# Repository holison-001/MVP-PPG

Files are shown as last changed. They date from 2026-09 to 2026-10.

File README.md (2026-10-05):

# SleepBud PPG PCB v0.8 — 회로도 갱신 (2026-10-06)

현재 [회로도](kicad/ppg_pcb_v08.kicad_sch)는 **C15·C16 100nF/16V/X7R/미터0603 MLCC를 각각 3V3–GND에 추가**한 41레퍼런스 설계입니다. 앞선 LDO_EN–PA7 연결과 J10 GND·J11 3V3 VTref 패드도 포함했습니다. D6·D7의 SWDIO·SWCLK 보호 연결은 유지합니다. **원본 회로도 ERC 오류·경고0건**을 확인했습니다.

[전체 회로도 미리보기](docs/review_schematic_20261006/schematic.png) · [C15·C16 확대](docs/review_schematic_20261006/capacitors_detail.png) · [변경 내용·현재 상태](docs/SCHEMATIC_UPDATE_20261006.md) · [검증 기록](docs/verification_schematic_20261006/)

**PCB 라우팅은 중지 상태입니다. 이번 커밋은 회로도와 관련 소스만 갱신하며, 저장소의 PCB·거버·BOM은 이전 단계 자료로 현재 회로도와 동기화되지 않았습니다.** 공유 설계 소스에는 작업 중인 6층·배치 설정도 포함되어 있으므로 현재 커밋을 배선·제조 완료본으로 사용하면 안 됩니다.

<details>
<summary>이전 Git PCB 기록 — 2026-10-01, 현재 회로도와 미동기화</summary>

# SleepBud PPG PCB v0.8 — RS-422, D2/D4 삭제

D2·D4 SM712를 삭제한 **37레퍼런스(구매 부품28개 + 구리 패드9개)** 회로입니다. U3 XR33194/U6 XR33183, R3 `120/1%` 종단, R4 `10k` 풀업, R5–R8 `22` 직렬저항은 유지합니다. 탑면에는 PPG U1만 배치합니다.

주 [PCB 파일](kicad/ppg_pcb_v08.kicad_pcb)에 RS-422 배선을 반영했습니다. **ERC0, DRC 오류0·미연결0·회로도 불일치0**이며 NRST까지 연결했습니다. 독립 검사에서도 부품 본체/조립 여유 겹침0, 패드·배선·비아–외곽 최소0.302168mm를 확인했습니다. 1층 GND 푸어는 외곽0.20mm 이격으로 확장했습니다. 실크 외곽4건·U2 라이브러리 도형 불일치1건의 경고는 [검증 기록](docs/verification_rs422_no_bus_tvs/)에 남겼습니다.

| 층 | 현재 구성 |
|---|---|
| 1층 F.Cu | PPG U1만 실장, 배선 18.80 mm, GND 푸어 102.64 mm², 외곽 이격0.20 mm |
| 2층 In1.Cu | 일부 신호 배선과 GND 푸어88.03 mm² |
| 3층 In2.Cu | 3V3 전체 푸어 제거, **0.40mm 전원 배선**과 NRST·SWDIO·12V·RS-422 일부 배선 |
| 4층 B.Cu | 나머지36레퍼런스와 부품 팬아웃 배선 |

1층 배선을2층으로 추가 이동해 **60.90→18.80 mm (69.1% 감소)**로 줄였고 GND 푸어는 **86.57→102.64 mm²**로 늘렸습니다. 새 비아 없이 기존 연결을 사용했습니다. 1층의 신호–푸어 간격0.15 mm·외곽 이격0.20 mm, 3층의0.40 mm 3V3 배선은 유지합니다. PCB 중심은 **40×40 mm 시트의(20,17) mm**로 이동했고 부품 상대 위치는 같습니다. [도면 시트 화면](docs/pcb_sheet.png), [층 변경·검토 사항](docs/PCB_layers_20261001.md). PCB와 함께 [사용자 규칙 파일](kicad/ppg_pcb_v08.kicad_dru)을 보관해야 푸어 이격이 유지됩니다.

- [회로도](kicad/ppg_pcb_v08.kicad_sch), [회로도 PDF](docs/ppg_pcb_v08_schematic.pdf)
- [탑·바텀 배치 PNG](docs/placement_preview_rs422/rs422_top_bottom.png), [D2/D4 제거 전후](docs/placement_preview_rs422/d2_d4_removed_comparison.png)
- [1층 PNG](docs/layers_png/01_F_Cu_TOP.png), [2층 PNG](docs/layers_png/02_In1_Cu_GND.png), [3층 PNG](docs/layers_png/03_In2_Cu_3V3.png), [4층 PNG](docs/layers_png/04_B_Cu_BOTTOM.png)
- [변경·핀 연결·케이블 표](docs/RS422_update_20261001.md), [이번 검증 원자료](docs/verification_rs422_no_bus_tvs/)
- [BOM 검토본](bom/MVP-PPG_BOM_부품별통합_DNP제외_값표준화_v2.xlsx): 승인 절차 지정 전에 생성한19그룹·37레퍼런스 자료
- [D2/D4 삭제 전39 회로 이력](docs/legacy_rs422_with_sm712/), [LVDS 배선·제조 이력](docs/legacy_before_rs422/)

**거버·BOM의 추가 생성/갱신은 사용자 승인 후 진행합니다.** [출력 승인 규칙](docs/OUTPUT_APPROVAL.md). 기존 `gerber/`와 루트 Gerber ZIP은 LVDS 이력으로 새 RS-422 제조 자료가 아닙니다.

검증 실행: `source /workspace/.amp-env/activate.sh` 후 `./kicad/run_v08.sh --check-only`. 기본 실행도 검증 전용입니다. 거버·BOM 출력은 명시적 승인 후 `--publish-approved-outputs` 옵션으로 진행합니다.

AMP 프로브 공급은 공칭9V이며 PPG의 기존 `12V_IN`/`12V` 넷 이름은 유지했습니다. D1·FB1 전원 보호와 D6–D8 SWD 보호는 유지하고 통신선 외부 TVS는 생략했습니다. SWDIO=J7, SWCLK=J8, NRST=J9입니다.

`ppg_rs422_review.*`와 `docs/review_rs422_pending/`는 NRST가 남아 있던 이전 검토 스냅샷입니다. 기존 좌표 CSV·STEP·옛 렌더 파일은 제조 자료 갱신 대상이며, 최신 배치/구리는 위에 연결한 PCB·배치 PNG·층별 PNG를 사용합니다.

</details>

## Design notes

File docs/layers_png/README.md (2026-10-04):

# RS-422 PCB 레이어 검토 PNG

현재 PCB에서 직접 출력한 검토 이미지입니다. 탑면과 내층은 위에서 본 방향, 바텀면은 부품 쪽에서 본 방향으로 좌우 반전했습니다. 배선 확인을 위해 구리와 보드 외곽만 표시하며, 부품 레퍼런스는 [별도 배치도](../placement_preview_rs422/rs422_top_bottom.png)에서 확인합니다.

- [01_F_Cu_TOP.png](01_F_Cu_TOP.png): TOP: GND pour and local traces, viewed from top
- [02_In1_Cu_GND.png](02_In1_Cu_GND.png): Layer 2: selected routing and GND pour, viewed from top
- [03_In2_Cu_3V3.png](03_In2_Cu_3V3.png): Layer 3: broad 3V3 traces and routing, viewed from top
- [04_B_Cu_BOTTOM.png](04_B_Cu_BOTTOM.png): BOTTOM copper, viewed from bottom, mirrored

[도면 시트 내 PCB 위치](../pcb_sheet.png)도 별도로 출력했습니다.

거버·BOM을 생성하지 않는 검토 출력입니다. 원본 PCB와 이미지 해시는 `source_manifest.json`에 기록했습니다.

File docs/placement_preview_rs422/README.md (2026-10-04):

# RS-422 부품 배치 화면

현재 37부품(1개 탑 / 36개 바텀)의 저장된 배치 도형을 표시합니다. D2·D4 제거 상태이며 탑면 U1 위치·방향은 유지합니다.

- `rs422_top_bottom.png`: 현재 탑/바텀 배치. **배치 형상 검증 통과 · 배선 미표시**.
- `d2_d4_removed_comparison.png`: 이전 39부품 SM712 구성과 현재 37부품 비교.
- `bottom_before_after.png`: 과거 LVDS 배치와 현재 RS-422 비교. LVDS 그림은 이력 참고입니다.
- `history_sm71239/`: 이전 39부품 후보의 원본 좌표·도형·검증 결과.

각 면을 부품 쪽에서 직접 본 방향입니다. 바텀은 KiCad 보드 좌표에서 좌우 반전했으며, J7 SWDIO / J8 SWCLK / J9 NRST를 외부 인출선으로 표시했습니다.

현재 형상 판정: 조립 여유 겹침 0쌍 · 최소 외곽 간격 0.305 mm / 요구 0.30 mm. 실제 본체 겹침은 0건입니다. 조립 여유 겹침은 빨강, 구리–외곽 간격 부족은 주황으로 표시합니다.

이 그림은 부품 배치 화면이며 배선·비아를 표시하지 않습니다. 형상 통과 표시는 배치 검사만 뜻하며 PCB 배선, 전기적 연결, 제조 검증의 완료를 뜻하지 않습니다.

Matplotlib·Shapely가 설치된 Python에서 `python3 render.py`로 다시 그릴 수 있습니다. 현재 클라우드 환경에서는 `PYTHONPATH=/workspace/.amp-env/python-extra python3 render.py`를 사용합니다. 임시 후보는 `--placement`, `--geometry`, `--audit`, `--output-dir` 옵션으로 별도 출력할 수 있습니다. 입력·출력 SHA-256은 `source_manifest.json`에 기록됩니다.

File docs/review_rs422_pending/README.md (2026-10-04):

# RS-422 배선 검토본 — NRST 1개 미연결

**이 폴더는 이전 검토 이력입니다.** 이후3층을 굵은 전원선과 신호 배선으로 변경해 미연결0건으로 마무리했습니다. 현재 상태는 [주 PCB](../../kicad/ppg_pcb_v08.kicad_pcb)와 [최신 층 변경 기록](../PCB_layers_20261001.md)을 확인하십시오. 아래 내용과 이미지들은 당시 스냅샷의 상태입니다.

`kicad/ppg_rs422_review.kicad_pcb`는 D2/D4를 삭제한 37레퍼런스 검토 스냅샷입니다. **아직 완료본이 아닙니다.** 주 PCB `ppg_pcb_v08.kicad_pcb`는 이전 LVDS 이력이며, 검증을 통과한 뒤 교체합니다. 회로도와 프로젝트 설정도 `ppg_rs422_review` 이름으로 함께 저장했습니다.

- TOP: PPG U1만 배치. BOTTOM: 나머지 36레퍼런스.
- F.Cu/B.Cu: 신호 배선. In1.Cu: GND. In2.Cu: 3V3.
- UART 송수신과 I2C 연결 완료. 남은 연결은 U2.4 NRST와 J9/D8 쪽입니다.
- 새로 실행한 DRC: 일반 설계규칙 오류 0, **미연결 1**, 회로도 불일치 0, 경고 7. 전체 검증은 미연결 때문에 실패 상태입니다.
- 경고 7건: 단일 층에만 연결된 비아 2, 외곽 실크 간격 4, U2 라이브러리 도형 불일치 1. 최종 정리 대상입니다.
- 독립 도형 검사: 부품 본체/조립 여유 겹침 0, 최소 구리–외곽 0.302168 mm, 이종 넷 구리 간격 0.150000 mm, 비아 드릴–SMD 구리 0.026574 mm. 비아는 양면 텐팅했습니다.
- U3/C6 전원 패드 간격이 2 mm를 넘는 점은 최종 전원 귀환 검토에 남겨 두었습니다.

## 검토 이미지

이 이미지들은 위 검토용 PCB의 실제 구리 배선에서 출력했습니다. 부품 레퍼런스가 있는 기존 배치 PNG는 이전 배치이므로 이 검토본의 최종 좌표를 나타내지 않습니다.

- [TOP](layers_png/01_F_Cu_TOP.png)
- [In1 GND](layers_png/02_In1_Cu_GND.png)
- [In2 3V3](layers_png/03_In2_Cu_3V3.png)
- [BOTTOM](layers_png/04_B_Cu_BOTTOM.png) — 바텀에서 본 방향으로 반전
- [4층 PDF](ppg_pcb_v08_layers.pdf) — 모든 층을 탑에서 본 방향

## 남은 배선

현재 배치에서 J9 둘레 반경 0.55–0.90 mm의 비아 후보 2,540개를 검사했지만, 다른 넷 구리 간격 또는 드릴–패드 간격을 만족하는 후보가 없었습니다. 이는 검사한 영역의 결과이며 모든 배치에서의 불가능성을 뜻하지 않습니다. C5를 왼쪽으로 조금 옮기는 예비 후보 7개는 남아 있으며, NRST 배선까지 함께 검증한 완료안은 아닙니다.

[탐색 결과](RESULT.md), [J9 링 검사](j9-ring-results.json), [C5 예비 후보](left-feasible-poses.json), [DRC](drc.json), [독립 검사](independent_audit.json), [이미지 원본 해시](layers_png/source_manifest.json)를 함께 보관했습니다.

C5 예비 위치와 5V_LED 배선을 함께 조정한 추가 검사에서는 NRST 연결 자체는 가능했지만 5V_LED를 모두 복구하지 못했습니다. [추가 검사 기록](nrst_c5_power_repair_attempts.json)을 남겼으며, 이 불완전한 시도들은 검토용 PCB에 반영하지 않았습니다. 다음 단계는 외층 배선을 위한 배치 조정 범위를 넓히거나, GND 내층을 유지하면서 3V3 내층 일부를 신호 배선에 사용하는 안을 검토하는 것입니다.

거버·BOM은 사용자 승인 전까지 추가 생성하거나 갱신하지 않습니다. 이 폴더의 PCB·이미지·검증 결과는 검토용입니다.

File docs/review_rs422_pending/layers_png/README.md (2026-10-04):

# RS-422 PCB 레이어 검토 PNG — NRST 미연결 1개

현재 PCB에서 직접 출력한 검토 이미지입니다. 탑면과 내층은 위에서 본 방향, 바텀면은 부품 쪽에서 본 방향으로 좌우 반전했습니다. 배선 확인을 위해 구리와 보드 외곽만 표시하며, 부품 레퍼런스는 이전 [배치도](../../placement_preview_rs422/rs422_top_bottom.png)에서 참고할 수 있습니다. 이전 배치도는 현재 검토본의 최종 좌표가 아닙니다.

- [01_F_Cu_TOP.png](01_F_Cu_TOP.png): TOP copper, viewed from top
- [02_In1_Cu_GND.png](02_In1_Cu_GND.png): Inner GND, viewed from top
- [03_In2_Cu_3V3.png](03_In2_Cu_3V3.png): Inner 3V3, viewed from top
- [04_B_Cu_BOTTOM.png](04_B_Cu_BOTTOM.png): BOTTOM copper, viewed from bottom, mirrored

거버·BOM을 생성하지 않는 검토 출력입니다. 원본 PCB와 이미지 해시는 `source_manifest.json`에 기록했습니다.

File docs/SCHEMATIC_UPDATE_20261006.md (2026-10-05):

# 회로도 반영 — 2026-10-06

사용자 요청에 따라 검증된 수정본을 `kicad/ppg_pcb_v08.kicad_sch`에 반영했습니다. SHA256은 `22710326102d073aed07db366af5cdf9c524c24e60d454332f31763870915f17`입니다.

- C15·C16: 각각 100nF, 16V, X7R, 미터 0603(0.6×0.3mm, 인치 0201) MLCC. 핀1은 3V3, 핀2는 GND입니다. 특정 제조사 MPN은 미확정입니다.
- D6·D7은 각각 SWDIO·SWCLK 보호 연결을 유지합니다. D8은 NRST 보호입니다.
- 앞선 작업의 U1.3 LDO_EN–U2.12 PA7 연결과 J10 GND·J11 3V3 VTref 패드도 이번 Git 회로도에 포함했습니다.
- 전체 41레퍼런스(부품30개·구리 패드11개), 번호 있는 핀123개입니다. 직전 검토 회로도의 기존119핀 연결과 부품·핀 UUID는 유지하며 C15·C16의4핀만 추가했습니다.

원본 경로에서 KiCad10.0.5 ERC를 실행해 오류·경고0건을 확인했습니다. 전체 A3 회로도와 커패시터 추가 영역의 텍스트·기호 및 용지 범위를 확인했습니다.

[회로도](../kicad/ppg_pcb_v08.kicad_sch) · [전체 미리보기](review_schematic_20261006/schematic.png) · [C15·C16 확대](review_schematic_20261006/capacitors_detail.png) · [검증 기록](verification_schematic_20261006/)

PCB 라우팅은 사용자 지시로 중지한 상태입니다. 이번 커밋은 회로도, 회로도 생성 소스와 필요한 풋프린트, 검증·미리보기만 게시합니다. 저장소의 PCB·프로젝트·거버·BOM은 이전 단계 파일이며 이번 회로도와 동기화된 완성본이 아닙니다. 회로도 ERC 통과를 PCB 배선 완료나 제조 승인으로 해석하면 안 됩니다.

`design_v08.py`는 회로와 PCB가 공유하는 설계 소스여서 6층 설정 및 작업 중인 부품 배치 정보도 포함합니다. 여기의 좌표·면 정보는 이번 커밋에 보존된 PCB와 일치한다고 보증하지 않으며, 현재 상태로 PCB 재생성·제조 출력을 완료본으로 사용할 수 없습니다. 중지 시점의 로컬 PCB 수정안은 C15·C16의3V3 연결2개가 남아 있으며 이번 Git 업로드에서 제외했습니다.

회로도 재생성에 필요한 변경 파일은 `design_v08.py`, `build_sch_v08.py`, `layout_schematic_v08.py`입니다. 새 SWD 패드 속성이 참조하는 `SleepBud.pretty/TestPad_D0.8_Front.kicad_mod`도 포함합니다. PCB 배선 파일이나 기존 제조 출력을 이번 요청으로 변경·게시하지 않았습니다.

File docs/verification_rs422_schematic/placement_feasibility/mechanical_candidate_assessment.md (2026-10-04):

# RS-422 mechanical candidate — not feasible

This is the best recorded candidate from the final strict geometry search. It is exploratory evidence only and must not be promoted to the PCB or used for manufacturing. The candidate has 39 components: U1 alone on the top and 38 on the bottom.

| Exact check | Result | Limit |
|---|---:|---:|
| Bottom courtyard sum | 118.924434 mm² | PCB circle 143.138815 mm² |
| Courtyard overlap | 0.513177 mm² across 44 pairs | 0 |
| Maximum copper radius | 6.487091 mm | ≤6.450000 mm |
| Minimum copper-to-edge clearance | 0.262909 mm | ≥0.300000 mm |
| Maximum physical body radius | 6.505333 mm | ≤6.750000 mm |
| Maximum courtyard radius | 6.868650 mm | ≤7.000000 mm |
| Body overlap pairs | 0 | 0 |
| Pad copper gap below 0.15 mm | 0 | 0 |

Copper edge violations: C14, C6, C7, D1, FB1, J2, J3, J4, J5, J6, R3.

The largest courtyard overlap is D4–R8 (0.144088 mm²), followed by J2–U4 (0.053836 mm²) and FB1–U3 (0.042516 mm²). All 44 overlapping pairs and all radius violations are listed in `mechanical_candidate_assessment.json`.

Courtyards retain their original geometry. Cable and test pads, which have no explicit library courtyard, use a 0.15 mm margin around copper. The final search used 45-degree orientations, zero anchor/link preference weights and progressively increased physical-edge penalties. Body constraints and the copper clearance requirement were preserved; courtyard overhang up to 0.25 mm was permitted.

This bounded search did not find a valid layout. It does not prove that a 13.5 mm layout is impossible. No candidate PCB or fabrication output was promoted.

Candidate: `packing_strict_best.json`  
Candidate SHA-256: `95d9c8068b0f0b0511ca408d00d770494a73f921b54c0765b2f53cc1873843b5`  
Geometry: `packing_geometry_physical.json`  
Geometry SHA-256: `decd3631b51500bb6cff86787ae325c2378f71cdacd3383167c65e1842ca838c`

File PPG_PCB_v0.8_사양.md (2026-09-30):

# PPG PCB v0.8 – UART over LVDS (TTL→LVDS / LVDS→TTL 변환칩) (2026-09-15)

> 사용자 요청: RS-485 대신 **TTL↔LVDS 소형 변환칩**으로 UART 링크를 구현할 것.
> 총괄 기록: 상위 `Device_design.md` 3.16절.

## 구성
| 블록 | 부품 | 패키지 | 역할 |
|---|---|---|---|
| TTL→LVDS 드라이버 | **U3 TI SN65LVDS1DBVR** | SOT-23-5 (2.9×1.6) | UART_TX(MCU PA9) → LVDS 쌍 **TXP/TXN** → 컨트롤러 |
| LVDS→TTL 리시버 | **U6 TI SN65LVDT2DBVR** | SOT-23-5 | 컨트롤러 → LVDS 쌍 **RXP/RXN** → UART_RX(MCU PA10). **110 Ω 종단 내장**(외부 종단저항 불필요) |
| MCU / LDO / PPG | STM32C011F6U6, MCP1703A ×2 (12→5→3.3 V), MAXM86161 | – | v0.7과 동일 |

핀 배치(데이터시트 SLLS373M 확인): SN65LVDS1 – 1 VCC, 2 GND, 3 Z(−), 4 Y(+), 5 D. SN65LVDS2/LVDT2 – 1 VCC, 2 GND, 3 A(+), 4 B(−), 5 R.
전원 2.4~3.6 V(3V3 레일 직결), 입력은 5 V 톨러런트 LVTTL, 출력 차동 ±350 mV(100 Ω 부하), ESD 버스 핀 ±9 kV.

### 동작·전기적 특성
- **전이중**: 송신·수신 경로가 분리되어 방향 제어 없음 → v0.7의 Q1/R4/R5 자동 방향전환 회로 삭제. STM32 USART 부트로더 그대로 동작.
- **유휴 상태 안전**: SN65LVDT2는 입력 개방/드라이버 OFF 시 출력 High(개방회로 페일세이프) → 컨트롤러 전원이 꺼지거나 케이블이 빠져도 UART_RX가 High(유휴)로 유지.
- **노이즈**: 차동 전송이라 공통모드 잡음에 강함. 단, 진폭이 ±350 mV로 RS-485(±1.5 V↑)보다 작으므로 **LVDS 쌍은 꼬임선(트위스트 페어)**으로, 12 V 전원선·압전 동축과 분리 배치 권장.
- **접지 전위차**: 드라이버–리시버 간 접지 오프셋 허용 |±1 V| (리시버 공통모드 0.05~2.45 V @3.3 V). 케이블 GND를 공유하므로 1~2 m 케이블에서는 문제 없음.
- **속도**: 부품 한계 400 Mbps → UART 보레이트 제한 없음(115.2 kbps~수 Mbps). 케이블 길이 1~2 m OK.
- 컨트롤러 쪽도 같은 한 쌍(SN65LVDS1 + SN65LVDT2)으로 대칭 구성하면 된다.

## 케이블
**+12V, GND, TXP, TXN, RXP, RXN = 6선 + 압전 동축** (v0.7 4선 → 6선. LVDS는 단방향 쌍이므로 전이중에는 2쌍 필요).
보드 패드 Ø1.2 ×6: 12V(좌하), GND(하단), TXP/TXN(우측 림, 드라이버 Y/Z 바로 옆), RXP/RXN(좌측 림, 리시버 A/B 바로 옆).

## MCU 디버깅 핀
뒷면 테스트 패드 Ø0.8 ×3: **SWDIO, SWCLK**(MCU 우측), **NRST**(MCU 좌측). GND·3V3는 케이블 패드 공용.

## 치수
| | v0.7 | **v0.8** |
|---|---|---|
| 외형 | Ø13 | **Ø13.5 mm** (4층 0.8 mm) |
| 부품 포함 두께 | ≈3.0 | **≈3.5 mm (최대 3.65)** = PCB 0.8 + 앞면 MAXM86161 1.4 + 뒷면 SOT-23-5 0.9~1.45 (v0.7의 SOT-5X3 0.6 → 두께 약 +0.5 mm) |
| 케이블 | 4선 + 동축 | **6선 + 동축** |
| 부품 | IC 5 + Q 1 + 수동 13 | **IC 6 + 수동 12** |

치수 변경 요약: **Ø13 → Ø13.5, 두께 ≈3.0 → ≈3.5 mm.** Ø13.5가 된 이유: LVDS 단일 드라이버/리시버는 **SOT-23-5(풋프린트 4.2×3.5 mm)** 또는 SOIC-8뿐이라, v0.7의 THVD1400(SOT-5X3 1.6×1.2) + SOT-323 조합보다 점유 면적이 약 2.5배 크다. Ø13에서는 코트야드 충돌·자동배선 실패 → Ø13.5에서 배선 성공.

## 부품 변경 (v0.7 대비)
- 삭제: Q1 2N7002PW, R3 120 Ω, R4/R5 10 kΩ, U3 THVD1400.
- 추가: U3 SN65LVDS1DBVR, U6 SN65LVDT2DBVR, C7 100 nF(U6 VCC 바이패스), 케이블 패드 2개(RXP/RXN).
- 배치: MCU 우측에 SWD 패드, 좌측에 NRST 패드; C12(3V3 벌크) MCU 우상단으로 이동.

## 검증
KiCad 10 DRC **0 오류 / 0 미연결**, ERC 전기 오류 0, 회로도↔설계데이터↔PCB 115 패드 넷 일치. Freerouting 자동배선(0 unrouted), 배선 분포 F.Cu 32 / B.Cu 147 / In1 2 / In2 2 / via 21.

## 파일
`ppg_pcb_v08_gerber.zip`, `docs/`(BOM, 좌표, 회로도·레이어 PDF, 3D 렌더, STEP), `kicad/`(`design_v08.py` 단일 설계 데이터, `run_v08.sh` 원클릭 파이프라인).

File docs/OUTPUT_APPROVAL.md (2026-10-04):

# 제조·BOM 출력 승인

사용자 요청(2026-10-01)에 따라 **거버와 BOM 생성·갱신은 명시적 승인 후 진행**합니다. PCB·회로도 편집, ERC/DRC·연결 검증, 배치·레이어 검토 이미지는 계속 진행할 수 있습니다.

현재 bom/의37부품 엑셀은 이 지시 전에 생성한 검토본입니다. 기존 거버는 LVDS 이력입니다. 새 RS-422 제조용 거버는 아직 만들지 않았습니다.

`kicad/run_v08.sh`의 기본 실행과 `--check-only`는 검증만 수행합니다. 제조·BOM 출력에는 `--publish-approved-outputs` 옵션이 필요하며, 이 옵션은 사용자의 명시적 승인 후에만 사용합니다. 옵션 자체가 승인을 대신하지 않습니다. 승인 대기 시점의 파일 해시는 `verification_rs422_no_bus_tvs/output_approval_status.json`에 기록했습니다.

`kicad/export_review_v08.py`는 PCB 검토용 레이어 PNG/SVG/PDF만 출력하며 거버·드릴·BOM을 생성하지 않습니다.

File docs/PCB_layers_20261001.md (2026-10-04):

# 2층 신호 배선 및 도면 시트 내 PCB 이동

1층의 비아 사이 배선 41개 구간·42.103 mm를 2층으로 옮겼습니다. UART_TX/RX, TXP_DRV/TXN_DRV, TXP와 SDA/SCL/5V_LED의 분기 구간이 대상입니다. PPG 패드에서 첫 비아로 나가는 배선은 1층에 남겼고, 2층에 SDA 연결선 1개를 추가했습니다. 새 비아 없이 기존59개를 사용했으며 부품 상대 위치·값·패드 넷·기존 트랙 폭을 유지했습니다.

| 항목 | 변경 전 | 현재 |
|---|---:|---:|
| 1층 배선 길이 | 60.902 mm | **18.799 mm (69.1% 감소)** |
| 1층 배선 세그먼트 | 69 | 28 |
| 1층 GND 푸어 면적 | 86.571 mm² | **102.636 mm² (18.6% 증가)** |
| 2층 배선 길이 | 0 mm | 43.971 mm, 42개 세그먼트 |
| 2층 GND 푸어 면적 | 104.802 mm² | 88.032 mm² |
| 비아 수 | 59 | 59 |

면적은 KiCad가 채운 GND 폴리곤에서 구멍을 제외한 CAD 면적입니다. 배선 길이는 트랙 중심선 합계이며 비아 수직 길이는 제외합니다. 1층 GND는 한 영역, 2층 GND는 두 영역으로 채워집니다. 두 층의 GND 영역과25개 GND 패드·18개 GND 비아는 하나의 전기망으로 연결되며 고립된 구리 섬은 없습니다.

## 층 구성과 간격

- 1층: PPG U1만 실장. PPG 연결과 GND 배선을 남기고 나머지는 GND 푸어. 신호–푸어 간격0.15 mm, 외곽 이격0.20 mm.
- 2층: 이동한 신호 배선과 GND 푸어. 신호–푸어 간격0.20 mm, 외곽 이격0.30 mm.
- 3층: 기존0.40 mm 3V3 전원선과 신호 배선 유지. 푸어 없음. 3V3 패드14개 모두 U5.1까지 연결.
- 4층: 나머지36레퍼런스와 기존 배선 유지.

1층 GND 외곽 규칙은 `kicad/ppg_pcb_v08.kicad_dru`에 있으므로 PCB·프로젝트와 함께 보관해야 합니다. 패드·트랙·비아에는 기존0.30 mm 외곽 이격을 유지합니다.

## 도면 내 위치

PCB 중심을 **40×40 mm 도면의 X=20 mm, Y=17 mm**로 이동했습니다. Ø13.5 mm 외곽은 X=13.25–26.75 mm, Y=10.25–23.75 mm에 있습니다. 그리드 원점과 보조 원점도 PCB 중심으로 옮겼습니다. 부품·배선·비아·외곽·푸어를 함께 평행 이동했으므로 상대 배치는 같습니다. 배치 검토도와 독립 기구 검사는 PCB 중심을(0,0)으로 환산하여 표시합니다.

시트 크기는 PCB 편집기의 페이지 설정에서 사용자 지정40×40 mm로 저장했습니다. 작은 표제란은 `kicad/ppg_compact.kicad_wks`를 사용합니다. PCB 실제 지름과 배선 형상은 변경하지 않았습니다.

[도면 시트 화면](pcb_sheet.png), [층별 PNG](layers_png/), [배치 PNG](placement_preview_rs422/rs422_top_bottom.png).

## 검증

37레퍼런스·117핀·48넷을 확인했습니다. DRC 오류0·미연결0·회로도 불일치0이고 독립 구리·기구 검사도 통과했습니다. 기존 ERC 오류·경고0인 회로도는 변경하지 않았습니다. 남은 DRC 경고5건은 U4/U5 실크 외곽4건과 U2 라이브러리 도형 불일치1건입니다.

최소 이종 넷 구리 간격0.150000 mm, 패드·트랙·비아–외곽0.302168 mm, 드릴–SMD 구리0.026574 mm, 드릴 사이0.377895 mm를 유지했습니다. 모든 비아는 양면 텐팅입니다. VREF 배선과 기존 U3/C6 디커플링 검토 사항은 유지했습니다.

[이동 기록](verification_rs422_no_bus_tvs/in1_routing_changes.json), [도면 좌표 기록](verification_rs422_no_bus_tvs/sheet_placement.json), [현재 독립 검사](verification_rs422_no_bus_tvs/independent_final_audit.json), [변경 전 보드](legacy_before_in1_routing/).

거버·BOM은 생성하거나 갱신하지 않았습니다. 사용자 승인 후 제조 출력을 진행합니다.

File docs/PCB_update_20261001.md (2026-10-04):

# MVP-PPG PCB 반영 기록 — 2026-10-01

D1–D8·FB1을 현재 회로도에 맞춰 배치하고 배선을 완료했다. 탑면은 U1(MAXM86161) 하나이며 U1의 원점·0° 배치를 유지했다. 보드 외경은 13.5 mm, 4층이다. 기존 PCB 파일에 사양과 달리 1.6 mm로 저장된 두께를 원설계의 0.8 mm로 수정했다. 구체적인 제조사 유전체 적층은 별도로 확정하지 않았다.

## 전기적 변경

- `/12V_IN`: J1.1, D1.1, FB1.1. `12V`: FB1.2, C13.1, U4.8. 비드 앞뒤를 별도 넷으로 배선했다.
- D1.2 및 D2–D8.2는 GND. D2–D8.1은 각각 TXP, TXN, RXP, RXN, SWDIO, SWCLK, NRST이다.
- TVS 8개는 각각 폭 0.20 mm·길이 약 0.525–0.570 mm의 GND 연결과 별도 0.50/0.25 mm 관통 비아를 가진다.
- In1.Cu는 GND, In2.Cu는 3V3 평면이다. 모든 배선 세그먼트는 F.Cu/B.Cu에 있다. 자동 배선에서 In1.Cu에 들어간 5V_LED 두 구간(합계 약 3.543 mm)을 F.Cu로 옮겨 GND 평면의 연속성을 확보했다.
- 총 183개 배선 세그먼트·34개 비아. 최소 배선 폭은 0.10 mm이다. MCU UART_RX 탈출부에는 이 최소 폭을 사용했다.
- 부품 이동에 맞춰 배선을 다시 연결하고, C4의 VLDO 탈출 공간을 확보하도록 C1/C4/C5 GND 연결을 조정했다.

## 배치 변경

기존 26개 레퍼런스 중 위치 또는 회전이 바뀐 15개이다. 단위 mm, KiCad 보드 좌표 기준이다. 표에 없는 기존 부품의 위치·회전·면은 유지했다.

| Ref | 이전 (x, y) / 회전 | 현재 (x, y) / 회전 |
|---|---|---|
| C4 | (-1.0, 0.85) / 90° | (-0.85, 0.85) / 90° |
| C5 | (1.0, 0.85) / 90° | (0.85, 0.85) / 90° |
| C6 | (4.5, -3.3) / 90° | (4.87, -3.4) / 90° |
| C7 | (-3.0, -2.5) / 180° | (-3.0, -3.4) / 180° |
| C11 | (-2.7, -3.8) / 180° | (-2.7, -4.35) / 180° |
| C12 | (2.7, -4.9) / 180° | (2.45, -5.1) / 90° |
| J1 | (-4.4, 3.85) / 180° | (-4.39, 3.85) / 180° |
| J5 | (-5.6, 1.3) / 180° | (-5.8, 0.5) / 180° |
| J6 | (-5.7, -1.0) / 180° | (-5.49, -2.0) / 180° |
| J9 | (-4.7, -2.6) / 180° | (-4.85, -3.1) / 180° |
| R1 | (-1.0, -0.65) / 90° | (-0.85, -0.65) / 90° |
| R2 | (1.0, -0.65) / 90° | (0.85, -0.65) / 90° |
| U2 | (0.0, -4.0) / 0° | (0.27, -4.0) / 0° |
| U3 | (3.3, 0.1) / -90° | (3.0, 0.1) / -90° |
| U6 | (-3.3, 0.1) / 90° | (-3.05, -0.82) / 90° |

추가 9개 부품 D1–D8·FB1은 모두 바텀면이다. 전체 35개 위치는 [좌표 CSV](ppg_pcb_v08_positions.csv), 비교 원자료는 [placement_changes.json](verification_v08/placement_changes.json)에 있다. 바텀면 미리보기는 부품을 직접 보는 방향으로 X축을 반전해 표시했다.

## 검증과 출력

KiCad 10.0.6으로 현재 회로도 XML을 새로 추출해 부품·111개 번호 패드·44개 넷·UUID 경로·필드를 비교했다. DRC 결과는 오류 0, 미연결 0, 회로도 불일치 0이다. 회로도 ERC도 위반 0이다. 드릴이 SMD 패드를 침범하는 경우와 같은 넷 비아끼리 겹치는 경우는 0이다.

남은 경고 6건은 기존 U4/U5 실크가 마스크에 잘리는 5건, U2의 기존 실크 제거로 인한 라이브러리 차이 1건이다. DRC 규칙을 완화하거나 경고를 숨기지 않았다. 실크 출력에는 솔더마스크 개구 차감을 적용했다.

- Gerber·Excellon 드릴·드릴 도면 18개를 ZIP으로 묶었고 ZIP 내용과 개별 파일 일치를 확인했다.
- 좌표 35개에서 top=U1, bottom=34개를 확인했다. 구리 패드 J1–J9도 좌표와 BOM에 포함된다.
- PCB PDF 7페이지, 회로도 PDF 1페이지, 앞뒤 SVG, 통합 BOM 16그룹·35레퍼런스를 갱신했다.
- BOM은 DNP 0이며 저항 `4.7k/1%`, 커패시터 F 생략, 패키지명과 데이터시트 파일명 표기를 유지했다. 알려진 R/C 보충 사양의 근거는 BOM 출처 JSON에 기록했다.
- 현재 STEP은 부품을 제외한 기판 모델이다. 공칭 기판 0.8 mm와 별개로 KiCad 기본 동박·마스크 표현을 포함한 STEP의 Z 범위는 약 0.81 mm이며 제조사 확정 적층을 의미하지 않는다. 과거 부품 포함 STEP·렌더·라우팅 세션은 `legacy_before_esd/`로 옮겼다.

검증 파일은 이 폴더의 [verification_v08](verification_v08/)에 있다. `netcheck_v08.py`는 부품·넷·면뿐 아니라 두께 0.8 mm·4층·원형 외경도 검사하므로 기존 두께 불일치의 재발을 탐지한다. 기본 `run_v08.sh`는 현재 배선 PCB를 보존하고 검증을 통과한 출력만 갱신한다.

## 실제 시험에서 확인할 항목

D1 `SPHV15-01ETG`의 명시 클램프 전압 22 V @ 1 A는 U4 `MCP1703A`의 입력 절대최대 18 V보다 높다. 회로도에 지정된 부품은 유지했다. FB1·C13 후단의 잔류 과도전압과 보드 ESD 내성은 실제 시험으로 확인해야 한다. 이번 검증은 회로도 일치·배치·배선 규칙 검사이며 ESD 시험이나 LVDS 신호 무결성 측정 결과를 의미하지 않는다. 선정 근거 링크는 [README](../README.md)에 있다.

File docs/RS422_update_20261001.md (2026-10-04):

# MVP-PPG RS-422 변경 — D2/D4 삭제

현재 회로는 **37레퍼런스(구매 부품28개 + 구리 패드9개)**입니다. 사용자 요청에 따라 D2/D4 SM712를 회로에서 삭제했습니다. DNP 처리한 부품이 아닙니다. Ø13.5 mm·4층·0.8 mm와 **탑면 U1 단독** 조건을 유지합니다.

## 반영한 회로

| 위치 | 부품·값 | 연결·기능 |
|---|---|---|
| U3 | XR33194ESBTR, TSOT-23-6 | AMP U402와 동일한 RS-422 송신기, 최대2.5Mbps |
| U6 | XR33183ESBTR, TSOT-23-6 | AMP U403과 동일한 RS-422 수신기, fail-safe idle high |
| R3 | `120/1%`, 0402 HP 0.2W | 케이블 측 RXP–RXN 종단 |
| R4 | `10k`, 0201 | UART_TX–3V3 풀업 |
| R5–R8 | `22`, 0402 HP 0.2W | 송수신 각 선의 직렬저항 |
| D2/D4 | 삭제 | RS-422 통신선에 외부 TVS 없음 |
| D1, FB1 | 유지 | 전원 입력 보호·필터 |
| D6–D8 | 유지 | SWDIO·SWCLK·NRST 보호 |

U3: 1 DI=UART_TX, 2 VCC=3V3, 3 DE=3V3, 4 Z=TXN_DRV, 5 GND, 6 Y=TXP_DRV. U6: 1 VCC=3V3, 2 GND, 3 RO=UART_RX, 4 B=RXN_RCV, 5 /EN=GND, 6 A=RXP_RCV. 송수신기는 항상 활성화합니다. C6/C7 디커플링을 유지합니다.

R5/R6은 TXP_DRV/TXN_DRV와 케이블 TXP/TXN 사이, R7/R8은 RXP_RCV/RXN_RCV와 케이블 RXP/RXN 사이입니다. R3는 **R7/R8의 케이블 쪽**에 연결합니다. 기존 MCU·PPG·LDO 회로의 부품 값과 핀 연결은 바뀌지 않았습니다.

## 케이블·디버그 패드

| AMP J403/J404 핀 | AMP 신호 | PPG 접점 |
|---:|---|---|
| 1 | +9V_PROBE1/2 | J1, 12V_IN |
| 2 | GND | J2, GND |
| 3/4 | TX± | J5/J6, RX± |
| 5/6 | RX± | J3/J4, TX± |
| 7 | DET | 현재 대응 회로 없음 |

AMP의 공급은 공칭9V입니다. PPG의 `12V_IN`/`12V`는 기존 넷 이름이며 공급전압을12V로 변경한 것이 아닙니다. 신호쌍의 극성은 유지하고 TX와 RX를 교차 연결합니다.

SWD 패드는 **J7=SWDIO, J8=SWCLK, J9=NRST**입니다. 최신 배치도에서 신호명을 함께 표시합니다.

## 검증과 파일

회로도 ERC 오류·경고0건. 37레퍼런스·117핀·48넷을 확인했습니다. 이전39 회로도 대비 변경된 핀 노드는 D2/D4의6개뿐이며, 생존 부품의 값·핀 연결·회로도 UUID를 보존했습니다. BOM은 DNP 제외·동일 부품 레퍼런스 통합·패키지명·데이터시트 파일명·합의한 값 표기 규칙을 적용한 **19그룹·37레퍼런스**입니다.

최종 PCB의 기구·구리 검사: 코트야드/본체 겹침0, 패드·배선·비아 최소 외곽 간격0.302168mm(요구0.30mm), 1층 GND 푸어 외곽 간격0.200613mm(요구0.20mm), 이종 넷 구리 간격0.150000mm(요구0.15mm). DRC 오류0·미연결0·회로도 불일치0입니다. 경고5건은 실크 외곽4건과 U2 라이브러리 도형 불일치1건입니다.

사용자 요청으로3층 3V3 푸어를 제거하고0.40mm 전원선으로 연결했습니다. SWDIO·12V의1층 구간 일부를3층으로 옮기고 NRST를 연결했으며,1층 남는 영역은 GND 푸어로 채웠습니다.2층은 현재 일부 신호 배선과 GND 푸어를 함께 사용하며 탑면 U1 단독 배치는 유지합니다. [층 변경과 전원·VREF 검토 사항](PCB_layers_20261001.md).

RXP·RXN·RXP_RCV를 3층/바텀으로 옮긴 뒤, 남은 1층의 비아 간 배선을2층으로 추가 이동했습니다. 현재 1층 배선은18.799 mm, GND 푸어는102.636 mm²입니다. 신호–푸어 간격0.15 mm와 외곽 이격0.20 mm를 유지하며, PCB 전체를 40×40 mm 시트의(20,17) mm로 평행 이동했습니다. 부품 상대 배치와3층3V3 전원선은 같습니다.

- [회로도 PDF](ppg_pcb_v08_schematic.pdf), [엑셀 BOM](../bom/MVP-PPG_BOM_부품별통합_DNP제외_값표준화_v2.xlsx)
- [탑·바텀 배치](placement_preview_rs422/rs422_top_bottom.png)
- [이번 삭제 검증과 배치 원자료](verification_rs422_no_bus_tvs/)
- [D2/D4 삭제 전39 회로 이력](legacy_rs422_with_sm712/)
- [기존 LVDS 배선·제조 이력](legacy_before_rs422/)

배치·배선 규칙 검사는 실물의 ESD 내성·신호 품질·발열 시험을 대체하지 않습니다. R3/R5–R8 0402 HP의0.2W는70°C 전력 정격이며 더 큰 패키지와 같은 펄스 내량을 의미하지 않습니다. 통신선 외부 TVS는 사용자 요청으로 생략한 상태입니다.

거버·BOM의 추가 생성/갱신은 사용자 승인 대기입니다. 새 PCB의 배선 검증은 완료했으며 제조 출력은 보류합니다. [출력 승인 규칙](OUTPUT_APPROVAL.md)

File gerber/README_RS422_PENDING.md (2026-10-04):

# RS-422 manufacturing outputs awaiting approval

The main PCB now contains the routed 37-reference RS-422 design, with zero DRC errors, zero unrouted connections and zero schematic-parity differences. This Gerber directory and the root Gerber ZIP remain the prior LVDS outputs. They have not been regenerated and must not be used to manufacture the current PCB. New Gerber/BOM outputs require explicit user approval. Prior coherent manufacturing design: ../docs/legacy_before_rs422/.

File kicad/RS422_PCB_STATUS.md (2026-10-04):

# Current RS-422 PCB

`ppg_pcb_v08.kicad_pcb` is the routed 37-reference design without D2/D4. DRC errors, unrouted connections and schematic-parity differences are zero. Five existing advisory warnings remain documented in `../docs/verification_rs422_no_bus_tvs/`.

F.Cu contains U1, 18.799 mm of local routing and 102.636 mm² GND fill. In1.Cu contains 43.971 mm of selected routing and 88.032 mm² GND fill. Its two filled regions connect through the existing ground network. In2.Cu retains the 0.40 mm 3V3 tracks and selected routing, without a pour. All other components remain on B.Cu. There are 59 existing vias; no new vias were added.

The board center is at (20,17) mm inside the custom 40×40 mm sheet, with the auxiliary and grid origins at that point. Design-model placement and preview geometry remain relative to the PCB center. `board_coordinates_v08.py` handles translation for generation and read-only inspection.

F.Cu ground-to-signal clearance is 0.15 mm and ground-to-edge setback is 0.20 mm. Keep `ppg_pcb_v08.kicad_dru` beside the PCB/project. Other copper retains the 0.30 mm edge rule.

`ppg_rs422_review.*` is an earlier incomplete snapshot. Gerber/BOM payloads remain frozen until explicit user approval. See `../docs/PCB_layers_20261001.md` and `../docs/verification_rs422_no_bus_tvs/in1_routing_changes.json`.

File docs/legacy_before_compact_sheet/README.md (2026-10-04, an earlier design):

# 작은 시트로 변경하기 전

A4 시트와 PCB 중심(150,100) mm였던 이전 자료입니다. 현재 보드는 ../../kicad/ppg_pcb_v08.kicad_pcb를 사용합니다.

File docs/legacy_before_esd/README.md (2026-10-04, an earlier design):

# ESD 반영 이전 자료

이 폴더의 STEP·3D 렌더·회로도 이미지·DSN·SES는 2026-10-01 PCB 작업 전에 저장소에 있던 이전 26개 레퍼런스 자료입니다. D1–D8·FB1과 이번 재배치·배선·두께 보정이 반영되어 있지 않습니다.

현재 파일은 저장소 README의 링크를 사용하세요. 현재 PCB를 이 폴더의 라우터 세션으로 덮어쓰지 마세요.

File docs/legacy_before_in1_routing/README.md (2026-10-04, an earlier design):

# 2층 배선 및 도면 내 위치 이동 이전

2층 GND 전용, PCB 중심(0,0), 1층 외곽 이격0.20 mm였던 검토 이력입니다. 현재 보드는 ../../kicad/ppg_pcb_v08.kicad_pcb를 사용합니다. 거버·BOM 출력이 아닙니다.

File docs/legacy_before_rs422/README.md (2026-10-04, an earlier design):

# SleepBud PPG PCB v0.8 — ESD PCB 반영

2026-10-01 기준, 현재 회로도의 **D1–D8 TVS와 FB1을 PCB 배치·배선에 반영했습니다. 탑면에는 PPG 센서 U1만 유지합니다.**

Ø13.5 mm, 4층, 두께 0.8 mm이며 바텀면에 나머지 34개 레퍼런스를 배치했습니다. 전체 35개 레퍼런스에는 구리 케이블·디버그 패드 9개가 포함됩니다(실장 부품 26개).

## 반영 내용

- D1: `SPHV15-01ETG`, SOD-882 1.0 × 0.6 mm. D2–D8: `ESD351DPYR`, DFN1006 1.0 × 0.6 mm. 로컬 풋프린트와 `CablePad_D0.8`을 작성했습니다.
- FB1: `BLM15PX601SN1D`, 0402 / 미터 1005. `J1 / 12V_IN → FB1 → 12V / C13 / U4`로 입력 전원을 분리했습니다. D1은 비드 앞의 12V_IN–GND에 연결합니다.
- 각 TVS의 GND 패드에 별도 비아를 약 0.52–0.57 mm의 0.20 mm 배선으로 연결했습니다.
- U1의 위치·방향·탑면 배치를 유지하고, U2/U3/U6 및 일부 수동소자·케이블 패드를 이동해 바텀면 공간을 확보했습니다.
- 회로도 UUID 경로, 부품 필드, 풋프린트 식별자, NC를 포함한 패드 넷을 동기화했습니다.
- BOM은 DNP 제외·동일 부품 레퍼런스 통합·패키지명·데이터시트 파일명·합의한 값 표기를 적용했습니다.

## 검증 결과

| 항목 | 결과 |
|---|---:|
| 회로도/PCB 레퍼런스 | 35 / 35 |
| 탑면 / 바텀면 | U1 1개 / 34개 |
| PCB DRC 오류 / 미연결 / 회로도 불일치 | 0 / 0 / 0 |
| 회로도 ERC 오류·경고 | 0 |
| DRC 경고 | 6 |
| BOM | 16그룹 / 35레퍼런스 / DNP 0 |
| 최소 배선 폭 / 비아 직경·드릴 | 0.10 / 0.50·0.25 mm |

DRC 경고는 기존 U4/U5 실크가 마스크에 잘리는 5건과 기존 U2의 실크 제거에 따른 라이브러리 차이 1건입니다. 검사 규칙과 경고 수준을 낮추지 않았습니다. Gerber 출력 시 실크에서 솔더마스크 개구를 차감했습니다. 상세 결과와 변경 좌표는 [작업 기록](docs/PCB_update_20261001.md), [검증 원자료](docs/verification_v08/)에 있습니다.

## 현재 파일

- [KiCad PCB](kicad/ppg_pcb_v08.kicad_pcb), [회로도](kicad/ppg_pcb_v08.kicad_sch), [회로도 PDF](docs/ppg_pcb_v08_schematic.pdf)
- [탑면 배치](docs/placement_front.png), [바텀면 배치](docs/placement_back.png), [PCB 레이어 PDF](docs/ppg_pcb_v08_layers.pdf)
- [탑면 SVG](docs/layout_front.svg), [바텀면 SVG](docs/layout_back.svg), [부품 좌표 CSV](docs/ppg_pcb_v08_positions.csv)
- [통합 BOM 엑셀](bom/MVP-PPG_BOM_부품별통합_DNP제외_값표준화_v2.xlsx), [BOM 설명·표기 규칙](bom/README.md)
- [Gerber·드릴 ZIP](ppg_pcb_v08_gerber.zip), [개별 제조 파일](gerber/)
- [기판 외형·드릴 STEP](docs/ppg_pcb_v08_board_only.step): 부품 3D 모델을 포함하지 않습니다. 공칭 기판은 0.8 mm이며, STEP의 KiCad 기본 동박·마스크 표현을 포함한 Z 범위는 약 0.81 mm입니다.

ESD 추가 전 STEP·3D 렌더·라우터 세션은 [과거 자료 폴더](docs/legacy_before_esd/)에 보관했습니다. 부품을 포함한 최신 3D 조립 모델은 이번 출력에 포함하지 않습니다. `PPG_PCB_v0.8_사양.md`와 `docs/verification_20260930/`는 이전 설계 기록입니다.

## 다시 검증·출력하기

KiCad 10 CLI, `pcbnew`를 사용할 수 있는 Python, BOM용 Python의 `openpyxl`이 필요합니다.

```bash
# 이 클라우드 환경의 도구 경로
source /workspace/.amp-env/activate.sh
./kicad/run_v08.sh --check-only
./kicad/run_v08.sh
```

기본 실행은 현재 배선 PCB의 복사본을 검사한 뒤 BOM·좌표·Gerber·드릴·PDF·SVG를 갱신하며 원본 PCB와 회로도를 재생성하지 않습니다. 오류·미연결·회로도 불일치가 있으면 출력을 중단합니다. `KICAD_CLI`, `KICAD_PYTHON`, `BOM_PYTHON`으로 실행 파일 경로를 지정할 수 있습니다.

`design_v08.py`는 최종 배치 좌표를 포함합니다. `--rebuild`는 배치부터 자동 배선한 별도 후보를 만드는 명시적 옵션이며 `FREEROUTING`이 필요합니다. 검토된 배선의 원본은 현재 `.kicad_pcb`이며, 자동 재배선 결과에는 추가 조정·DRC가 필요할 수 있습니다.

## 부품 선정 근거와 실제 시험

- [TI ESD351 데이터시트](https://www.ti.com/lit/ds/symlink/esd351.pdf): 핀 1은 IO/cathode, 핀 2는 GND/anode입니다. 권장 랜드는 0.30 × 0.50 mm, 중심 간격 0.70 mm입니다.
- [Littelfuse SPHV 데이터시트](https://www.littelfuse.com/assetdocs/littelfuse_tvs_diode_array_sphv_datasheet.pdf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): SPHV15-01ETG의 핀 1은 cathode, 핀 2는 anode입니다. 권장 랜드는 0.325 × 0.650 mm, 중심 간격 0.650 mm입니다.
- [Murata BLM15PX601SN1 사양](https://www.murata.com/en-us/products/productdetail?partno=BLM15PX601SN1%23): 600 Ω @ 100 MHz, 85°C에서 0.9 A, 최대 DCR 0.23 Ω입니다.

D1의 클램핑 전압은 1 A에서 22 V로, [MCP1703A의 입력 절대최대값 18 V](https://ww1.microchip.com/downloads/en/DeviceDoc/20005122B.pdf)보다 높습니다. 비드와 C13 이후 U4 입력에 남는 과도전압은 실제 ESD 시험으로 확인해야 합니다. 부품 자체의 ESD 정격을 보드의 보증 내성으로 해석하지 않습니다.

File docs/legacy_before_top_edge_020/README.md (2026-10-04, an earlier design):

# 1층 GND 외곽 이격 변경 전

1층 GND 외곽 이격 0.30 mm, 신호 간격 0.15 mm였던 검증 완료 PCB입니다. 현재 보드는 ../../kicad/ppg_pcb_v08.kicad_pcb를 사용합니다. 거버·BOM 출력이 아닙니다.

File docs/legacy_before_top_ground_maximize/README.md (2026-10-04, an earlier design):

# 1층 GND 확대 전 검토 이력

2026-10-01, 1층 배선 최소화 요청 직전의 검증된 PCB 스냅샷입니다. 거버·BOM은 포함하거나 재생성하지 않았습니다. 당시 1층 배선 75구간·72.298 mm, GND 푸어 70.198 mm²이며 DRC 오류·미연결·회로도 불일치0건입니다. 최신 PCB는 저장소 kicad/ppg_pcb_v08.kicad_pcb를 사용합니다.

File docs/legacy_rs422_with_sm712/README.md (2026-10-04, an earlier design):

# D2/D4 제거 전 RS-422 회로 이력

SM712 D2/D4를 포함한 39레퍼런스 회로도·BOM·배치 검토 자료입니다. 배치·배선이 완료된 PCB 이력이 아닙니다. 현재 회로는 두 부품을 삭제한 37레퍼런스입니다.

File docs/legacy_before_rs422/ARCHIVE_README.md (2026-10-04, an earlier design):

# LVDS baseline before RS-422 circuit promotion

Complete prior kicad/, docs/, gerber/, bom/, ZIP, README and specifications are preserved. Original documentation and older history stay in their original relative paths. See MANIFEST.json for SHA-256 values.

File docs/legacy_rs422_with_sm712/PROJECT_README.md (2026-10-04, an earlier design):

# SleepBud PPG PCB v0.8 — RS-422 회로 반영

현재 회로도와 BOM은 **XR33194/XR33183 기반 RS-422 39개 레퍼런스**로 갱신했습니다. **PCB 반영은 대기(PENDING)**입니다. 탑면에는 PPG 센서 U1만 배치하는 조건을 유지합니다.

- [RS-422 회로도](kicad/ppg_pcb_v08.kicad_sch), [회로도 PDF](docs/ppg_pcb_v08_schematic.pdf), [미리보기](docs/rs422_schematic_preview.png)
- [통합 BOM 엑셀](bom/MVP-PPG_BOM_부품별통합_DNP제외_값표준화_v2.xlsx): 20그룹·39레퍼런스, 구매 부품 30개와 구리 패드 9개
- [변경·핀 연결·케이블 교차 연결·검증 범위](docs/RS422_update_20261001.md)
- [RS-422 탑·바텀 배치 검토 PNG](docs/placement_preview_rs422/rs422_top_bottom.png), [기존 LVDS와 바텀 비교](docs/placement_preview_rs422/bottom_before_after.png) — 배선 전·검증 미통과 후보
- [회로 검증 원자료](docs/verification_rs422_schematic/): ERC 0건, 39개 부품의 모델/넷리스트 일치
- [이전 LVDS 설계·제조·검증 이력](docs/legacy_before_rs422/)

## PCB와 제조 파일 상태

현재 `kicad/ppg_pcb_v08.kicad_pcb`는 **이전 LVDS 배선본**입니다. 현재 RS-422 회로도와 일치하지 않습니다. `gerber/`, 루트 Gerber ZIP, PCB 레이어·배치·좌표·STEP는 기존 LVDS 이력이며 RS-422 제조 파일이 아닙니다. 새로운 PCB 배치·배선·DRC·회로도 일치 검사 완료 후 함께 갱신해야 합니다. Ø13.5 mm 배치 탐색에서 조립 여유 영역의 겹침과 0.30 mm 외곽 간격 미달이 남아 PCB를 확정하지 않았습니다. [배치 검토 기록](docs/verification_rs422_schematic/placement_feasibility/)을 보관했습니다.

`run_v08.sh`는 현재 회로도와 PCB의 불일치를 검사하므로 미완성 조합에서 제조 출력을 생성하면 안 됩니다. `--rebuild`는 별도 후보 생성 기능이며 현재 PCB 반영 완료를 뜻하지 않습니다. 이 변경에서 PCB 재생성·Gerber 재출력은 수행하지 않았습니다.

## 전원과 보호

AMP의 프로브 공급은 공칭 +9 V입니다. PPG의 기존 `12V_IN`/`12V` 넷 이름은 그대로 두었으며 공급을 12 V로 바꾸지 않았습니다. AMP TX±는 PPG RX±로, PPG TX±는 AMP RX±로 극성을 유지하여 교차 연결합니다.

D2/D4 SM712 및 R5–R8 22 Ω 0402 HP를 적용하고, R3 120 Ω 종단은 수신기 직렬 저항 앞 케이블 측에 둡니다. 0402의 0.2 W 표기를 더 큰 AMP 저항과 동일한 펄스 내량으로 해석하지 않습니다. 최종 시제품에서 IEC 내성·잔류 전압·발열 검증이 필요합니다.

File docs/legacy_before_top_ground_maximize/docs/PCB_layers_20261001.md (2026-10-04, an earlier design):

# 3층 전원 배선 및 1층 GND 변경

사용자 요청에 따라3층의 3V3 전체 푸어를 삭제하고, 전원 비아10개를 **0.40 mm 배선**으로 연결했습니다. 총 전원 배선 길이는27.079 mm이며,3V3 패드14개 모두 레귤레이터 U5.1까지 실제 구리 연결을 확인했습니다. 검증 규칙은3층 3V3의 최소 폭0.30 mm를 요구하며 이번 보드에서는 전 구간0.40 mm를 사용했습니다.

SWDIO와12V의1층 비아 사이 구간 일부를3층으로 옮겼습니다.3층에서12V는0.30 mm, NRST와 SWDIO는0.10 mm입니다.1층 남는 영역은 GND 푸어로 채우고 연결되지 않은 구리 섬은 제거하도록 설정했습니다.2층 GND면은 유지했습니다.3층에는 푸어를 두지 않습니다.

이전 NRST 미연결 검토본에 비해 부품 위치·회전·값·패드 연결은 그대로입니다. MCU 주변3V3 비아를(-0.05, -0.25), GND 비아를(0.15, 0.95) mm로 옮겨 NRST 탈출 공간을 확보했습니다. NRST는3층을 사용해 완결했고, 사용하지 않는 단일 층 비아2개와 UART_TX의 막다른 배선을 정리했습니다. TXP의 바텀 연결은 짧은 구리 배선으로 유지했습니다.

## 검증

- 37레퍼런스·117핀·48넷, TOP에는 U1만 실장.
- ERC 오류/경고0. DRC 오류0·미연결0·회로도 불일치0.
- 독립 구리·기구 검사 통과: 최소 이종 넷 간격0.150000 mm, 구리–외곽0.302168 mm, 드릴–SMD 구리0.026574 mm, 비아 드릴 사이0.377895 mm.
- 비아59개, 모두 양면 텐팅. 부품 본체/조립 여유 겹침0.
- 남은 경고5건: U4/U5 실크 외곽4건, U2 라이브러리 도형 불일치1건. 구리 연결 오류와 별도로 기록했습니다.

VREF 외층 배선 길이는 이전 검토본의4.73 mm에서7.34 mm로 늘었습니다. U3/C6 전원 패드 간격이2 mm를 넘는 점과 함께 아날로그 잡음·디커플링 검토 사항으로 남깁니다. 이번 검증은 CAD 연결·간격 검사이며 실물 신호 품질 측정 결과는 아닙니다.

[PCB](../kicad/ppg_pcb_v08.kicad_pcb), [층별 PNG](layers_png/), [배치 PNG](placement_preview_rs422/rs422_top_bottom.png), [독립 검증](verification_rs422_no_bus_tvs/independent_final_audit.json), [DRC](verification_rs422_no_bus_tvs/drc_final.json).

거버·BOM 파일은 추가 생성하거나 갱신하지 않았습니다. 사용자 승인 후 제조 출력을 진행합니다.

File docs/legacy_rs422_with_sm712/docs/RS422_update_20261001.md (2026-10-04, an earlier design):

# MVP-PPG RS-422 회로 변경 — 2026-10-01

**회로도: 검증 완료. PCB: 반영 대기(PENDING). 이 문서의 회로 검증 결과를 PCB 또는 제조 승인으로 해석하지 않습니다.**

기존 LVDS 송신기·수신기를 MVP-AMP와 같은 MaxLinear RS-422 소자로 변경한 Ø13.5 mm 후보입니다. U1 PPG 센서 정의와 탑면 단독 배치 조건은 유지합니다. 새로운 바텀면 배치·배선과 제조 출력은 별도로 검증해야 합니다.

## 부품과 신호 변경

| 항목 | 이전 LVDS 설계 | RS-422 후보 |
|---|---|---|
| U3 | SN65LVDS1DBVR | XR33194ESBTR, 3.3 V ±5%, 2.5 Mbps |
| U6 | SN65LVDT2DBVR, 내부 110 Ω 종단 | XR33183ESBTR, 3.0–5.5 V, 외부 종단 필요 |
| U3/U6 패키지·랜드 | SOT-23-5 | TSOT-23-6, 제조사 권장 랜드 `SleepBud:TSOT23-6_MaxLinear` |
| 버스 TVS | D2–D5 ESD351DPYR | D2/D4 CDSOT23-SM712, 각각 두 회선; D3/D5 삭제 |
| R3 | 없음 | `120/1%`, CRCW0402120RFKEDHP, 0402, 0.2 W |
| R4 | 없음 | `10k`, 0201, UART_TX 풀업; 주문형번 미확정 |
| R5–R8 | 없음 | `22`, CRCW040222R0JNEDHP, ±5%, 0402, 0.2 W |

D1 전원 TVS, FB1, D6–D8 SWD 보호, MCU·PPG·LDO 부품은 유지합니다. 현재 회로도는 총 39개 레퍼런스이며 구리 케이블·디버그 패드 9개를 포함합니다. 이전 실제 설계 35개 중 D3/D5를 제외한 33개의 부품 UUID를 유지하고, R3–R8 6개를 추가했습니다.

### U3/U6 핀 연결

| IC | 핀 | 기능 | 연결 |
|---|---:|---|---|
| U3 XR33194 | 1 | DI | UART_TX |
| U3 | 2 | VCC | 3V3 |
| U3 | 3 | DE | 3V3 — 송신 항상 활성 |
| U3 | 4 | Z | TXN_DRV → R6 → TXN |
| U3 | 5 | GND | GND |
| U3 | 6 | Y | TXP_DRV → R5 → TXP |
| U6 XR33183 | 1 | VCC | 3V3 |
| U6 | 2 | GND | GND |
| U6 | 3 | RO | UART_RX |
| U6 | 4 | B | RXN_RCV ← R8 ← RXN |
| U6 | 5 | /EN | GND — 수신 항상 활성 |
| U6 | 6 | A | RXP_RCV ← R7 ← RXP |

R4는 UART_TX–3V3에 연결하여 MCU 리셋 중 DI를 High로 둡니다. U6의 향상된 fail-safe 특성은 개방·단락·무구동 입력에서 RO를 High로 만듭니다. 실제 통신 속도는 느린 쪽인 XR33194의 2.5 Mbps와 펌웨어 설정에 맞춰야 합니다.

### 보호와 종단의 위치

- D2: 핀 1=TXP, 핀 2=TXN, 핀 3=GND.
- D4: 핀 1=RXP, 핀 2=RXN, 핀 3=GND.
- R5/R6: 각각 IC 측 TXP_DRV/TXN_DRV와 케이블 측 TXP/TXN 사이.
- R7/R8: 각각 IC 측 RXP_RCV/RXN_RCV와 케이블 측 RXP/RXN 사이.
- **R3는 케이블 측 RXP–RXN 사이에 연결합니다. 수신기 앞 22 Ω 저항 두 개의 IC 측에 배치하지 않습니다.**

SM712는 RS-422의 -7/+12 V 동작 범위를 고려한 비대칭 두 회선 TVS입니다. 3.6 V ESD351을 RS-422 버스에 그대로 두지 않습니다. SM712는 케이블 유입점에 가깝게, GND 귀환은 짧고 낮은 인덕턴스로 배치해야 합니다.

## AMP 케이블 교차 연결

AMP의 송신 쌍은 PPG 수신 쌍으로, PPG 송신 쌍은 AMP 수신 쌍으로 연결합니다. 극성 P/N은 유지합니다.

| AMP J403 또는 J404 핀 | AMP 신호 | PPG 접점 | PPG 신호 |
|---:|---|---|---|
| 1 | +9V_PROBE1 / +9V_PROBE2 | J1 | 12V_IN |
| 2 | GND | J2 | GND |
| 3 | TX1_P / TX2_P | J5 | RXP |
| 4 | TX1_N / TX2_N | J6 | RXN |
| 5 | RX1_P / RX2_P | J3 | TXP |
| 6 | RX1_N / RX2_N | J4 | TXN |
| 7 | PROBE_DET1_RAW / PROBE_DET2_RAW | 대응 접점 없음 | 별도 하네스·검출 설계 확인 |

AMP의 현재 프로브 전원 기준은 **공칭 +9 V**입니다. 이번 통신 회로 변경에서는 PPG의 기존 `12V_IN` 및 비드 뒤 `12V` 넷 이름을 유지했습니다. 이 이름이 AMP 전원을 12 V로 변경한다는 뜻은 아닙니다. 실제 하네스 전압, 전원 극성, 공통 GND, LDO 입력·발열은 조립 단계에서 확인해야 합니다.

## 검증 범위

| 확인 항목 | 결과 |
|---|---|
| KiCad 회로도 ERC | 오류·경고 0건 |
| 생성 회로도 ↔ design_v08.py | 39개 부품 전체 핀·넷 일치 |
| U3/U6 공급·활성화·차동 극성 | 위 핀 표와 일치 |
| D2/D4 보호 위치 | 케이블 측 회선과 GND 연결 확인 |
| R3 종단 위치 | R7/R8 앞 케이블 측 RXP/RXN 확인 |
| TSOT-23-6 랜드 | 제조사 권장 랜드 파일 사용; 실제 배치·DRC는 별도 |
| PCB DRC·미연결·회로도 일치 | **PENDING — RS-422 PCB 결과 없음** |
| Gerber·드릴·좌표·PCB PDF/STEP | **PENDING — 기존 파일은 LVDS 이력** |

원자료는 `docs/verification_rs422_schematic/`의 ERC JSON, 넷리스트 XML, 검증 요약에 보관합니다. 최종 내보내기에서 39레퍼런스·123핀·48넷을 확인했고, 통신 변경 대상 외 부품의 핀 연결은 이전 회로와 동일합니다. 기존 LVDS PCB에 `run_v08.sh --check-only`를 실행하면 회로도 불일치로 중단되며, PCB·Gerber ZIP·좌표 파일 해시가 그대로임을 확인했습니다. 회로도 검증은 부품 모델의 물리적인 보호 성능을 검증하지 않습니다.

## 소형 저항·보호 회로의 실물 검증

R3 및 R5–R8은 Vishay CRCW-HP 0402 0.2 W 부품입니다. 이 전력 표기가 AMP의 더 큰 저항과 같은 펄스·서지 에너지 내량을 보장하지 않습니다. 데이터시트의 펄스 폭·전압·에너지 한계, 기판의 방열과 주변 온도에 따른 정격 저감을 확인해야 합니다.

R4의 정상상태 손실은 3.465 V에서 약 1.20 mW입니다. R3는 종단 양단에 3.465 V와 저항 -1%를 보수적으로 가정하면 약 0.101 W이며, 실제 차동 진폭과 반대쪽 직렬 저항에 따라 달라집니다. 최종 저항 전압·온도는 실제 케이블 및 통신 조건으로 확인합니다.

SM712의 양(+) 방향 클램프는 최대 19 V @ 1 A, 26 V @ 17 A로, XR33194 출력·XR33183 입력의 절대최대 ±18 V보다 높습니다. 직렬 저항과 IC 내부 보호를 포함한 잔류 과도전압을 확인해야 합니다.

SM712 데이터시트의 개별 소자 정격이나 XR33194/XR33183의 ESD 정격을 완성 보드의 IEC 보증으로 사용하지 않습니다. **최종 시제품에서 IEC ESD/서지 조건과 기능 복귀, 잔류 전압, 저항 온도·손상을 검증해야 합니다.** 기존 D1/SPHV15과 U4 입력 보호 협조도 이번 통신 변경으로 검증된 항목이 아닙니다.

## 파일과 이전 자료

- 현재 RS-422 회로도: `kicad/ppg_pcb_v08.kicad_sch`
- 통합 BOM: `bom/` — DNP 제외, 레퍼런스 통합, 패키지 및 데이터시트 파일명 표기
- 회로도 PDF·미리보기: `docs/ppg_pcb_v08_schematic.pdf`, `docs/rs422_schematic_preview.png`
- 이전 LVDS 회로도·배선 PCB·제조 파일·검증 기록 전체: `docs/legacy_before_rs422/`

**PCB 상태 자리표시자:** 현재 `kicad/ppg_pcb_v08.kicad_pcb`는 기존 LVDS 배선본입니다. RS-422 회로도에 맞는 PCB 반영·배선·DRC 완료 후 이 문단과 제조 파일을 함께 갱신해야 합니다. 기존 Gerber ZIP, PCB 레이어·좌표·STEP·배치 그림은 RS-422 제조 자료로 사용하지 않습니다.

## PCB 배치 검토 결과

Ø13.5 mm·탑면 U1 단독 조건에서 수평·수직 및 45° 배치를 탐색했으나 검증을 통과한 배치를 찾지 못했습니다. 최종 후보는 코트야드 겹침 44쌍(합계 0.513177 mm²), 최소 구리–외곽 간격 0.262909 mm로 요구 0.30 mm를 충족하지 않습니다. 본체 겹침과 패드 간 0.15 mm 미만 간격은 없었습니다. 이 결과는 물리적 배치 불가능의 증명이 아니며, 추가 배치 최적화 또는 검증된 소형 보호소자 선정이 남았습니다.

탐색 후보와 정확 검사 기록은 [배치 검토 자료](verification_rs422_schematic/placement_feasibility/)에 보관합니다. 기준을 낮추거나 이 후보를 기존 PCB·Gerber에 적용하지 않았습니다. 회로도·BOM은 현재 RS-422 설계이고, 기존 PCB·제조 출력은 LVDS 이력입니다.

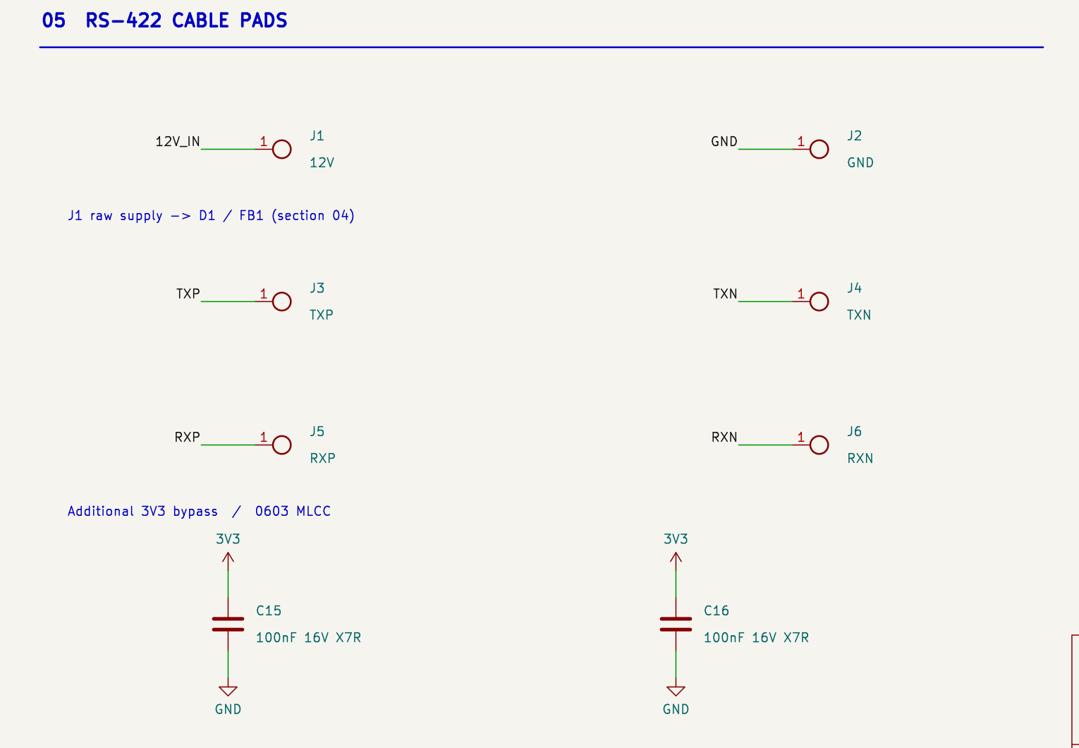
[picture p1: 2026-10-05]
docs/review_schematic_20261006/capacitors_detail.png

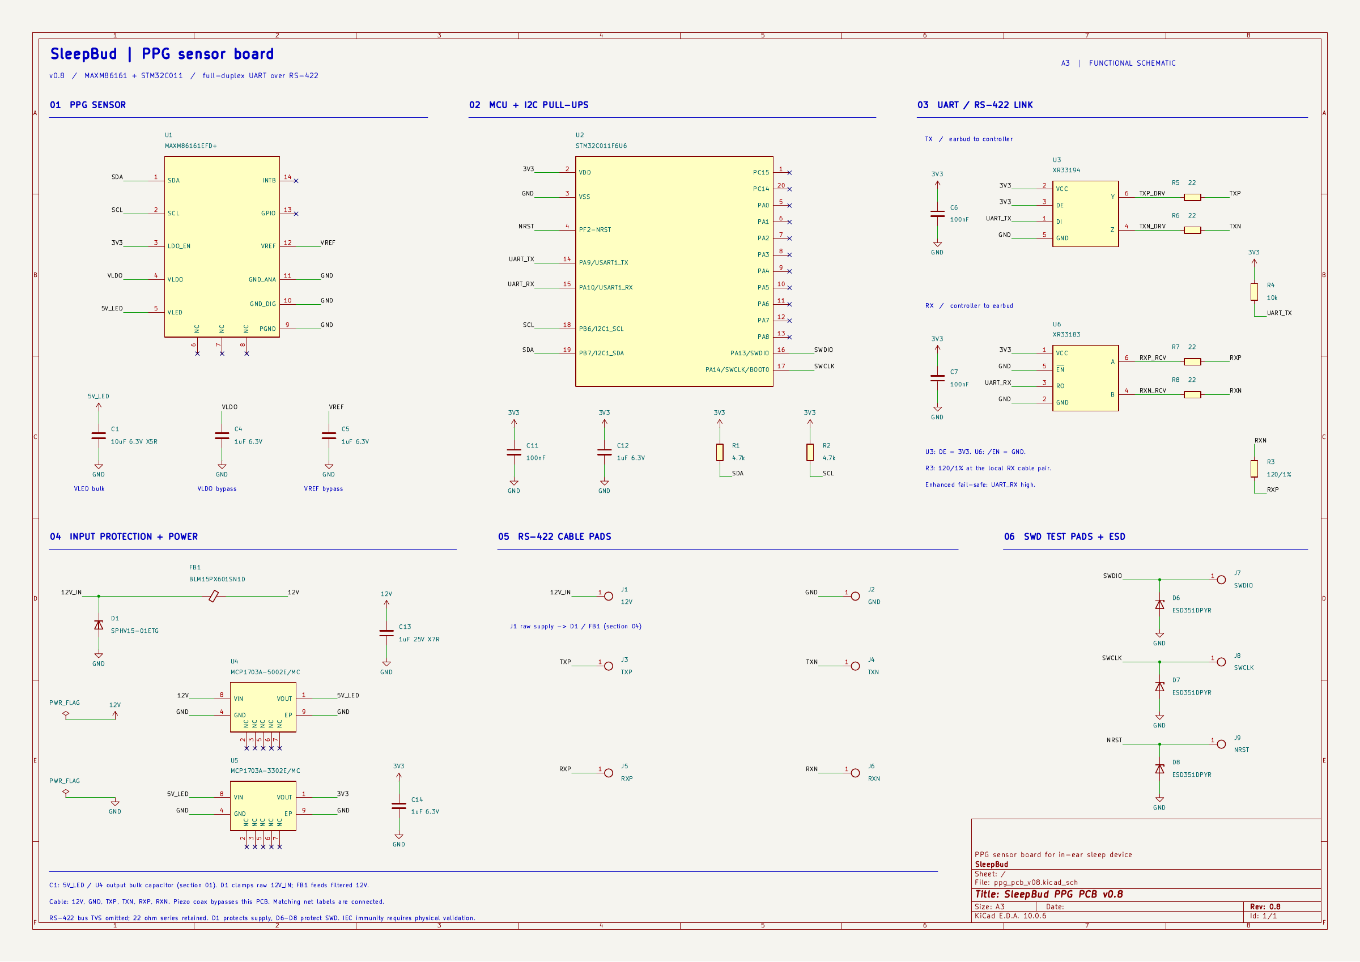
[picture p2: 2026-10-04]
docs/rs422_schematic_preview.png

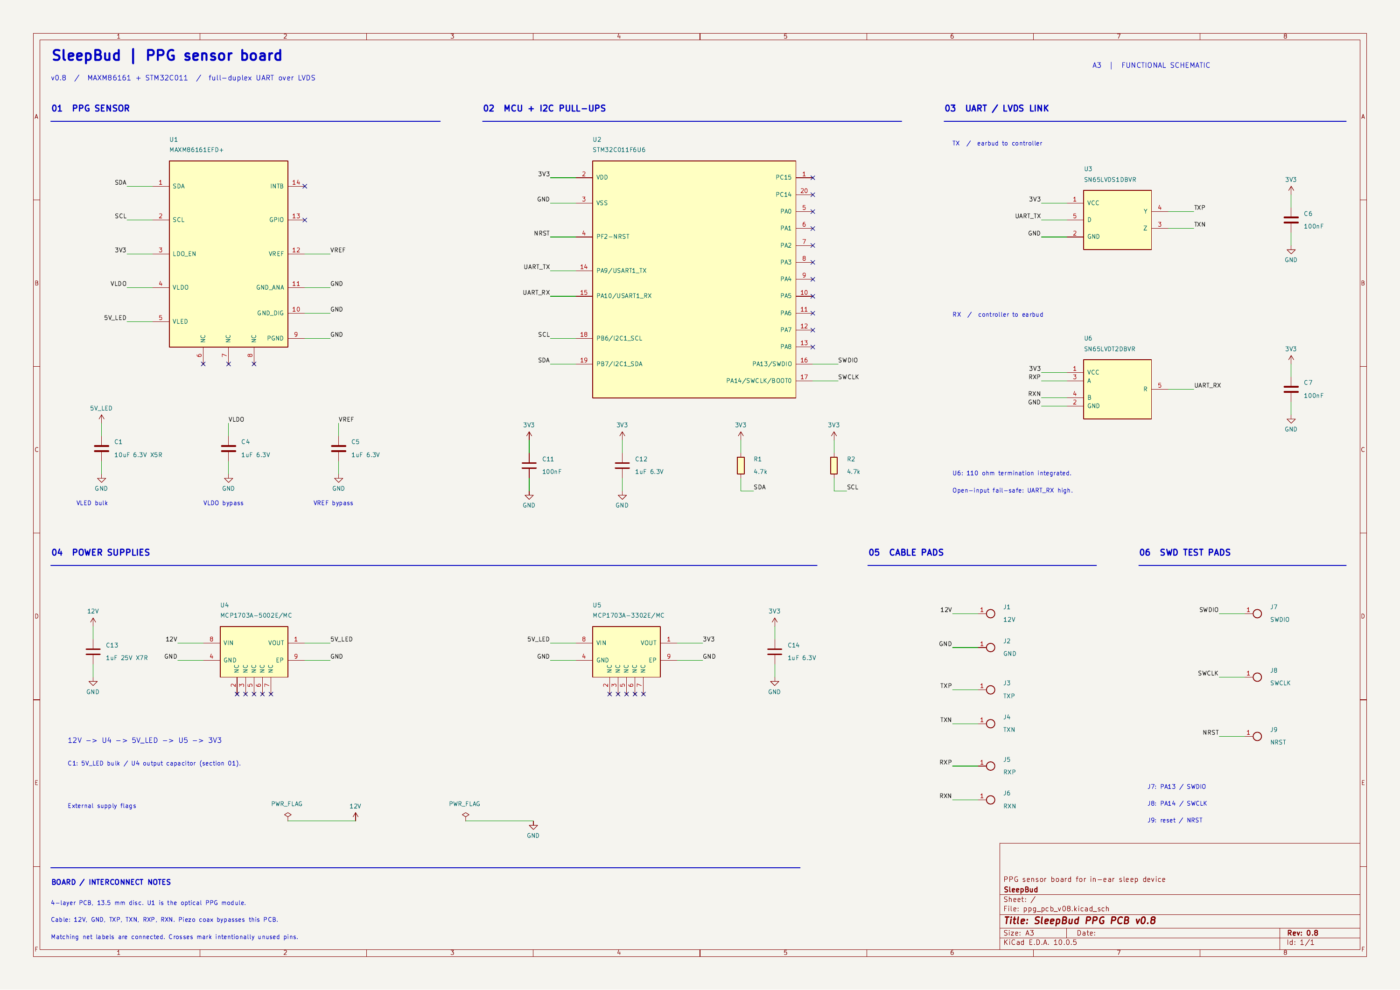
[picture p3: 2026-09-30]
docs/schematic_preview.png

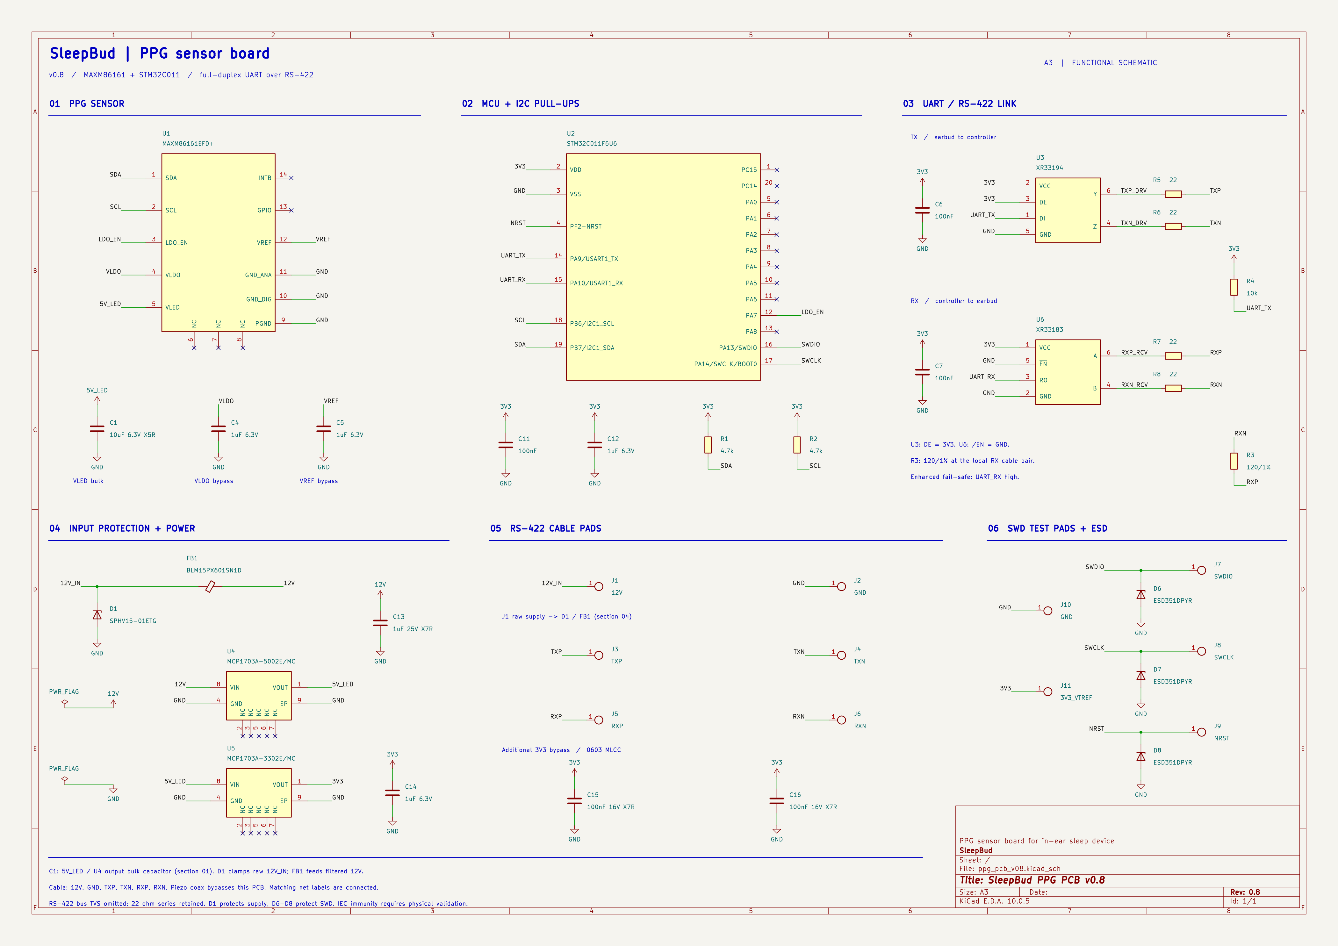
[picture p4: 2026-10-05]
docs/review_schematic_20261006/schematic.png

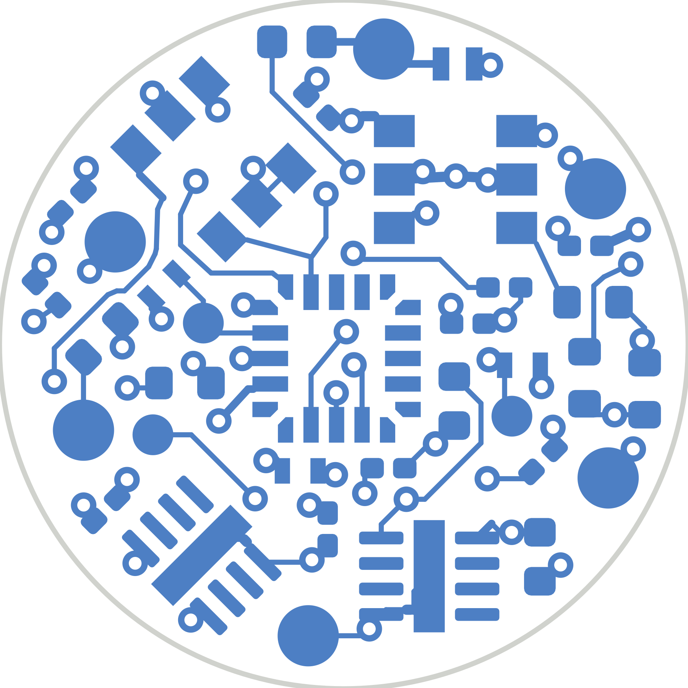
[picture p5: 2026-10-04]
docs/layers_png/04_B_Cu_BOTTOM.png

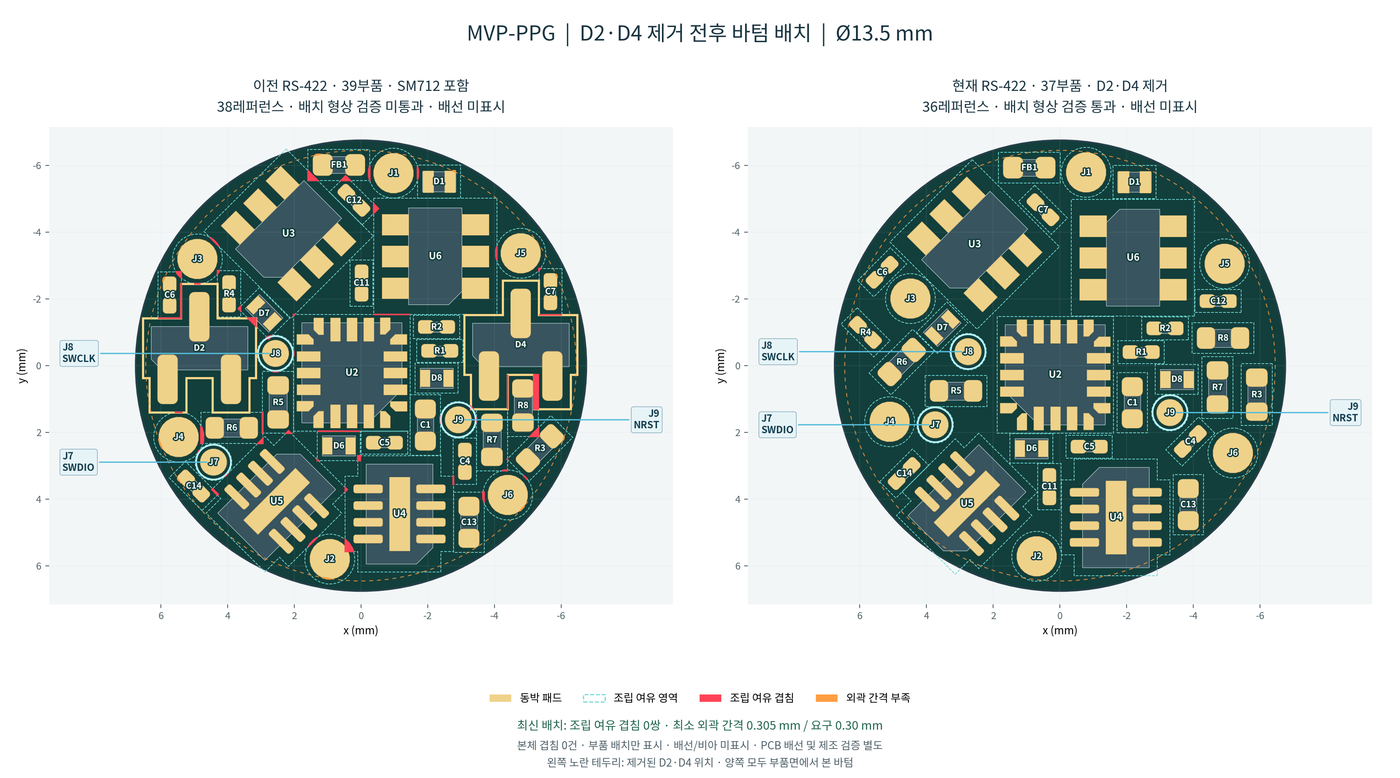
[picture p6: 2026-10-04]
docs/placement_preview_rs422/d2_d4_removed_comparison.png

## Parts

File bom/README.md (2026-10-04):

# MVP-PPG RS-422 회로도 BOM

현재 회로도 기준 **19그룹·37레퍼런스**이며, 구매 부품 28개와 구리 패드 9개를 포함합니다. DNP와 BOM 제외 항목은 제외하고 같은 부품은 레퍼런스를 모았습니다. 패키지명과 데이터시트 파일명 표기를 사용합니다.

저항은 Ω와 기본 5%를 생략하고, 다른 오차율은 `120/1%`처럼 표시합니다. 커패시터 F와 인덕터 H는 생략합니다. R4의 주문형번은 미확정이며, 값이 없는 기존 부품 사양을 추정하여 확정하지 않습니다.

- `MVP-PPG_BOM_부품별통합_DNP제외_값표준화_v2.xlsx`: 검토용 엑셀
- `ppg_pcb_v08_BOM.csv`: 동일한 표
- `bom_sources.json`: 원본 값·출처·그룹화 근거

기존 R1/R2의 1%, 커패시터 보충 사양은 이전 검토 규칙을 유지합니다. R3/R5–R8의 확정 MPN과 고유 사양에는 기존 보충값을 덮어쓰지 않습니다. 참고 PDF는 `../datasheet/pdf/`에 있습니다.

회로도 BOM이며 PCB 반영·제조 승인 상태를 보증하지 않습니다. [RS-422 변경 기록](../docs/RS422_update_20261001.md)을 확인하십시오. 다시 생성: `python kicad/bom_v08.py`(저장소 루트 기준).

D2/D4 SM712는 사용자 요청으로 회로에서 삭제되어 BOM에서도 제외했습니다. DNP 처리한 부품이 아닙니다. R3 종단, R4 풀업, R5–R8 직렬저항은 유지합니다.

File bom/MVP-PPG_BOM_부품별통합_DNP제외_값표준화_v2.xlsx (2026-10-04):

MVP-PPG BOM — 부품별 통합 · DNP 제외 · 값 표준 v2
현행 회로도 기준 | 19그룹 · 37개 레퍼런스(구리 패드 포함) | DNP 0개 · BOM 제외 0개
저항 Ω·커패시터 F·인덕터 H 생략. 저항 기본 5% 생략; 명시된 1%·0.1%는 /오차율로 표시. 패키지·데이터시트 파일명 표기.
예시 MPN은 비고에만 기록하며 PDF 원문은 포함하지 않습니다. 회로도 BOM이며 PCB 제조 검증 결과는 별도 확인합니다.
No. | 레퍼런스 | 수량 | 값 | MPN | 제조사 | 패키지 | 참고 데이터시트 | 비고
1 | C1 | 1 | 10u/6.3V/X5R |  |  | 0402 (1005) |  | MPN 미확정. 기존 BOM 예시: GRM155R60J106ME47 데이터시트 미연결
2 | C4, C5, C12, C14 | 4 | 1u/6.3V/X5R |  |  | 0201 (0603) |  | 기존 v0.8 BOM의 X5R MPN 미확정. 기존 BOM 예시: GRM033R60J105MEA2 데이터시트 미연결
3 | C6, C7, C11 | 3 | 100n/16V/X7R |  |  | 0201 (0603) |  | 기존 v0.8 BOM의 16V/X7R MPN 미확정. 기존 BOM 예시: GRM033R71C104KE14 데이터시트 미연결
4 | C13 | 1 | 1u/25V/X7R |  |  | 0402 (1005) |  | MPN 미확정. 기존 예시 GRM155R61E105KA12는 X7R 적합성 확인 필요 데이터시트 미연결
5 | D1 | 1 | SPHV15-01ETG | SPHV15-01ETG | Littelfuse | SOD-882, 1.0 × 0.6 mm | littelfuse_tvs_diode_array_sphv_datasheet.pdf
6 | D6, D7, D8 | 3 | ESD351DPYR | ESD351DPYR | Texas Instruments | DFN1006-2 (DPY), 1.0 × 0.6 mm | esd351.pdf
7 | FB1 | 1 | 600Ω@100MHz/0.9A | BLM15PX601SN1D | Murata | 0402 (1005) |  | 정격 0.9A @85°C, DCR 최대 0.23Ω PDF 미연결(제조사 제품 페이지)
8 | J1, J2, J3, J4, J5, J6 | 6 | 케이블 납땜 패드 |  |  | 구리 납땜 패드 Ø1.2 mm |  | 구리 패드 — 구매 부품 아님 J1=12V; J2=GND; J3=TXP; J4=TXN; J5=RXP; J6=RXN
9 | J7, J8, J9 | 3 | SWD 테스트패드 |  |  | 구리 테스트패드 Ø0.8 mm |  | 구리 패드 — 구매 부품 아님 J7=SWDIO; J8=SWCLK; J9=NRST
10 | R1, R2 | 2 | 4.7k/1% |  |  | 0201 (0603) |  | 기존 v0.8 BOM의 1% MPN 미확정 데이터시트 미연결
11 | R3 | 1 | 120/1% | CRCW0402120RFKEDHP | Vishay | 0402 (1005) | Vishay_CRCW-HP_e3.pdf | HP 펄스 대응 저항, 0.2W (P70). 실제 PCB 열·펄스·ESD 성능 검증 필요 주문형번은 제조사 코드 규칙 기준; 재고·수급 확인 전
12 | R4 | 1 | 10k |  |  | 0201 (0603) |  | MPN 미확정 데이터시트 미연결
13 | R5, R6, R7, R8 | 4 | 22 | CRCW040222R0JNEDHP | Vishay | 0402 (1005) | Vishay_CRCW-HP_e3.pdf | HP 펄스 대응 저항, 0.2W (P70). 실제 PCB 열·펄스·ESD 성능 검증 필요 주문형번은 제조사 코드 규칙 기준; 재고·수급 확인 전
14 | U1 | 1 | MAXM86161EFD+ | MAXM86161EFD+ | Analog Devices (Maxim) | OLGA-14, 2.9 × 4.3 mm |  | 기존 BOM: 지급품(consigned) 데이터시트 미연결
15 | U2 | 1 | STM32C011F6U6 | STM32C011F6U6 | STMicroelectronics | UFQFPN-20, 3 × 3 mm, P0.5 mm |  | 데이터시트 미연결
16 | U3 | 1 | XR33194 | XR33194ESBTR | MaxLinear | TSOT-23-6 | XR33193_XR33194_XR33195_MaxLinear.pdf
17 | U4 | 1 | MCP1703A-5002E/MC | MCP1703A-5002E/MC | Microchip | DFN-8, 2 × 3 mm, P0.5 mm (노출패드) | 20005122B.pdf | 데이터시트: 저장소 README 링크 기준
18 | U5 | 1 | MCP1703A-3302E/MC | MCP1703A-3302E/MC | Microchip | DFN-8, 2 × 3 mm, P0.5 mm (노출패드) | 20005122B.pdf | 데이터시트: 저장소 README 링크 기준
19 | U6 | 1 | XR33183 | XR33183ESBTR | MaxLinear | TSOT-23-6 | XR33180_XR33181_XR33183_XR33184_MaxLinear.pdf

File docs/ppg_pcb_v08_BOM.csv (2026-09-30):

Refs | Qty | Value | Footprint | Side | Part / note
U1 | 1 | MAXM86161EFD+ | MAXM86161_OLGA-14 | Top(F) | ADI MAXM86161EFD+ (consigned)
U2 | 1 | STM32C011F6U6 | ST_UFQFPN-20_3x3mm_P0.5mm | Bottom(B) | ST STM32C011F6U6 UFQFPN-20
U3 | 1 | SN65LVDS1DBVR | SOT-23-5 | Bottom(B) | TI SN65LVDS1DBVR LVDS driver SOT-23-5
U6 | 1 | SN65LVDT2DBVR | SOT-23-5 | Bottom(B) | TI SN65LVDT2DBVR LVDS receiver, 110 R termination, SOT-23-5
U4 | 1 | MCP1703A-5002E/MC | DFN-8-1EP_2x3mm_P0.5mm_EP0.61x2.2mm | Bottom(B) | Microchip MCP1703A-5002E/MC (2x3 DFN)
U5 | 1 | MCP1703A-3302E/MC | DFN-8-1EP_2x3mm_P0.5mm_EP0.61x2.2mm | Bottom(B) | Microchip MCP1703A-3302E/MC (2x3 DFN)
C1 | 1 | 10uF 6.3V X5R | C_0402_1005Metric | Bottom(B) | 0402 X5R 6.3V 10uF e.g. GRM155R60J106ME47
C4, C5, C12, C14 | 4 | 1uF 6.3V | C_0201_0603Metric | Bottom(B) | 0201 X5R 6.3V 1uF e.g. GRM033R60J105MEA2
R1, R2 | 2 | 4.7k | R_0201_0603Metric | Bottom(B) | 0201 1% 4.7k
C6, C7, C11 | 3 | 100nF | C_0201_0603Metric | Bottom(B) | 0201 X7R 16V 100nF e.g. GRM033R71C104KE14
C13 | 1 | 1uF 25V X7R | C_0402_1005Metric | Bottom(B) | 0402 X7R 25V 1uF e.g. GRM155R61E105KA12
J1-J6 | 6 | cable solder pads (12V, GND, TXP, TXN, RXP, RXN) | CablePad_D1.2 | Bottom(B) | hand-soldered cable (LVDS pairs twisted); piezo coax not on PCB
J7-J9 | 3 | SWD test pads (SWDIO, SWCLK, NRST) | CablePad_D0.8 | Bottom(B) | debug; GND/3V3 from cable pads

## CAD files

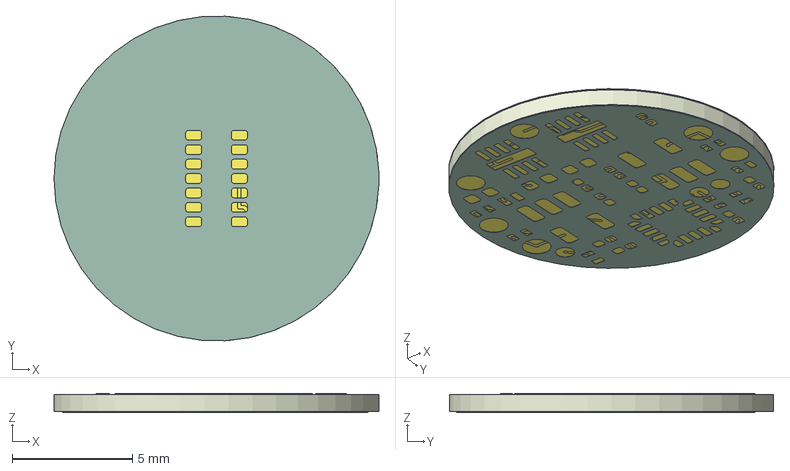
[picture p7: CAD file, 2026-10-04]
docs/ppg_pcb_v08_board_only.step
13.5 x 13.5 x 0.81 mm
ppg_pcb_v08_copper
ppg_pcb_v08_pad
ppg_pcb_v08_via
ppg_pcb_v08_soldermask x 2
ppg_pcb_v08_PCB

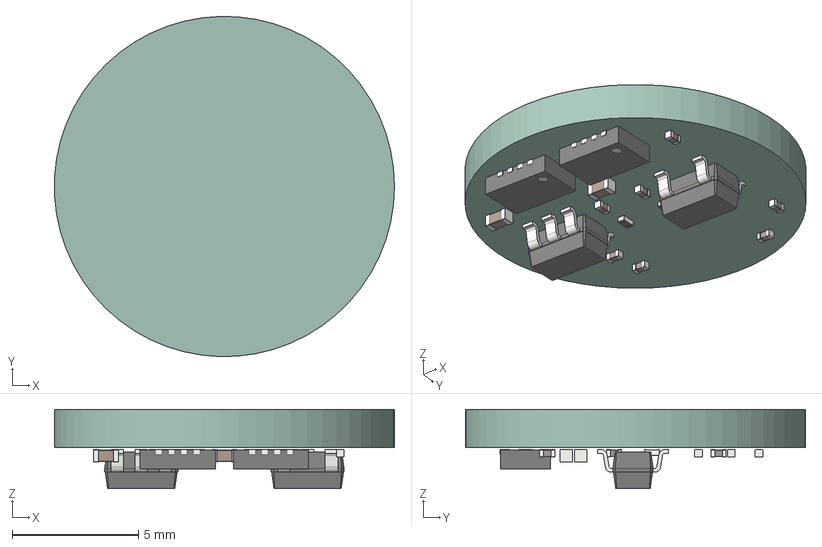
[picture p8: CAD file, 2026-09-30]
docs/ppg_pcb_v08.step
13.5 x 13.5 x 3.15 mm
SOT-23-5 x 2
C_0201_0603Metric x 7
R_0201_0603Metric x 2
C_0402_1005Metric x 2
DFN-8-1EP_2x3mm_Pitch0.5mm x 2
ppg_pcb_v08_PCB

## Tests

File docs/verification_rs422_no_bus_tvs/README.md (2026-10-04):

# 현재 RS-422 PCB 검증

회로도는37레퍼런스·117핀·48넷이며 ERC 오류·경고0입니다. 이전39 회로에서 D2/D4의6핀만 제거했고 나머지 부품 값·전기 연결·회로도 UUID는 유지했습니다. 이번 작업은 PCB의 배선층과 시트 위치 변경입니다.

현재 PCB는 DRC 오류0·미연결0·회로도 불일치0이며 독립 검사도 통과했습니다. `drc_final.json`, `netcheck_final.json`, `independent_final_audit.json`이 현재 결과입니다. `check_only.log`는 거버·BOM 출력을 하지 않는 기본 검증 실행 기록입니다.

1층 배선41개 구간·42.103 mm를2층으로 옮겼고 SDA 연결선1개를 추가했습니다. 1층 길이는60.902→18.799 mm, GND 푸어는86.571→102.636 mm²입니다. 2층은 신호와 GND 푸어88.032 mm²를 함께 사용합니다. 기존59개 비아·부품 상대 위치·값·패드 넷·트랙 폭과3층0.40 mm 3V3는 유지했습니다. `in1_routing_changes.json`과 `in1_ground_connectivity.json`을 참조합니다.

PCB 중심은 40×40 mm 시트의(20,17) mm이며 보조·그리드 원점도 같은 위치입니다. `sheet_placement.json`에 이동을 기록했습니다. `placement/`와 독립 검사 좌표는 저장 보드에서 PCB 중심을 빼서 환산한 상대 좌표입니다. [도면 시트 화면](../pcb_sheet.png).

탑면 U1만 실장, 바텀36개 배치를 유지합니다. 부품 본체/조립 여유 겹침0, 패드·트랙·비아 외곽 최소0.302168 mm, 드릴–SMD 구리 최소0.026574 mm입니다. 1층 GND 외곽 이격0.20 mm와 신호 간격0.15 mm는 `kicad/ppg_pcb_v08.kicad_dru`를 포함해 검증했습니다. 비아는 모두 양면 텐팅입니다.

남은 경고5건은 실크 외곽4건과 U2 라이브러리 도형 불일치1건입니다. VREF 배선과 기존 U3/C6 디커플링 검토 사항은 유지합니다.

현재 PCB SHA256: `a127537955e5888ac5311f0a84a54265dfcddba2ac4c5e0a987e3f0d69d3c238`. `output_approval_status.json`의 기존 거버·BOM23개 파일은 승인 전까지 동결합니다. 현재 검증 근거의 해시는 `final_source_manifest.json`에 있습니다.

이전 층 변경 기록인 `in2_3V3_routing.json`, `signal_layer_changes.json`, `top_ground_changes.json`, `top_edge_changes.json`은 이력입니다. 이번 변경 직전 파일은 `../legacy_before_in1_routing/`에 보관했습니다. [전체 층 구성과 변경](../PCB_layers_20261001.md).

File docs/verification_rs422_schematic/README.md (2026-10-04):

# D2/D4 삭제 전39 회로 검증 이력

이 폴더의 결과는 SM712를 포함한 이전39회로 검증입니다. 현재37 회로와 PCB 검증은 [최신 검증 폴더](../verification_rs422_no_bus_tvs/)를 확인하십시오.

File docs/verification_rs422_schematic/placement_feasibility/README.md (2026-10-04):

# RS-422 배치 탐색 — 검증 불합격

이 파일은 39개 부품 배치의 검토 기록이며 PCB 제조용 좌표가 아닙니다. 탑면 U1 고정, 나머지 38개 바텀, Ø13.5 mm 조건을 적용했습니다.

최종 후보: 코트야드 겹침 44쌍·0.513177 mm², 최소 구리–외곽 간격 0.262909 mm(요구 0.30 mm). 실제 본체 겹침과 패드 사이 0.15 mm 미만 간격은 없었지만 조립 여유·외곽 간격 기준을 통과하지 못했습니다. 배치 불가능의 증명은 아니며 추가 배치 최적화 또는 소형 보호소자 재선정이 남았습니다.

정확 판정: mechanical_candidate_assessment.json. 후보: packing_strict_best.json. 각 회전의 실제 도형: packing_geometry_physical.json. 원 보고서의 /workspace/ppg-rs422-work 경로는 탐색 당시 위치이며 같은 파일을 이 폴더에 보존했습니다. 후보는 회로도 모델을 PCB 배치로 승격하거나 Gerber로 출력하지 않았습니다.

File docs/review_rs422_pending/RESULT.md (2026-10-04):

# Finite NRST/C5 check

Best frozen PCB remains `../uart-complete/kicad/ppg_pcb_v08.kicad_pcb`: DRC errors 0; one NRST connection unfinished. This investigation did not change that PCB, the actual repository, BOM, or Gerber files.

C5 search: 728 poses, 52 mechanically legal, 7 provisionally legal against the current copper and via holes. Exact poses are in `left-feasible-poses.json`. These exclude the new NRST via (-0.5, 2.4), so they are not final routing solutions. The requested pose (-1.4, 2.4258), 180° fails at 0.0246549 mm foreign copper clearance due to nearby 5V_LED copper.

J9 search: radius 0.55–0.90 mm around (-3.2955, 1.4062), 0.025 mm grid, 2540 candidates. With C5 temporarily removed and 5V_LED F.Cu tracks removed, 2488 candidates fail foreign copper clearance and the remaining 52 fail the 0.025 mm nominal drill-to-pad gap with a 0.001 mm search margin. No legal candidate remained for a route attempt. Eleven compatible items from the earlier NRST solution were retained in memory; three conflicting terminal items were excluded. See `j9-ring-results.json`.

No search expansion or final manufacturing output was performed. The finite local check did not solve NRST.

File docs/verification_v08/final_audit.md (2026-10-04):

# Independent PCB audit — PASS

Audited `/workspace/ppg-pcb-work/stage/ppg_pcb_v08.kicad_pcb` read-only against the current repository schematic, design data, footprint libraries and original PCB. All audit inputs remained unchanged throughout validation.

| Check | Result |
|---|---|
| Schematic components / numbered pads / nets | 35 / 111 / 44; exact match |
| Component sides | U1 only on top; all other 34 on bottom |
| Power and TVS polarity | J1/D1/FB1.1 on 12V_IN; FB1.2/C13/U4 VIN on 12V; every TVS pin 1 signal, pin 2 GND |
| Sensor and footprints | U1 placement unchanged; all pad geometries preserved |
| Board | Diameter 13.5 mm; 4 copper layers; thickness 0.8 mm |
| Routing | 30 front and 153 back track segments; zero inner-layer track segments |
| Track and via dimensions | Minimum trace width 0.1 mm; 34 vias, all 0.5 mm / 0.25 mm drill |
| Via interference | No via drill over SMD copper; no same-net via-to-via overlap |
| TVS ground returns | All 8 dedicated vias and 0.2 mm direct traces preserved; length 0.525–0.570 mm |

Two ground vias have annular copper joining same-net pads, with their drills remaining outside the pads; this is not a drill interference. The independent audit reports no remaining issues. DRC is recorded separately.

The reusable net checker rejects incorrect board thickness, copper-layer count, circular board outline and any routed track segment on an inner layer. Incorrect thickness, layer count and an inner-layer track were detected in memory without saving a PCB.

Audited board SHA-256: `03709b49341c3901012be2a3edece03c8007b1238ee3284406bd707d44844c5a`

Schematic SHA-256: `cacd4a8d676d97b61cb60be985126533673ead4233c0b91e2fb304bb89bcadf3`

Design SHA-256: `39a60a1d9a6ea4ed8aa5c0c6b9a769795a27177670610c5391cc5554986667e8`

Full checks and hashes for every source input are in `final_audit.json`.

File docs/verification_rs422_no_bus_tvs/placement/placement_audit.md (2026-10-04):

# 37-component placement — mechanical checks pass

D2 and D4 were removed. U1 remains at (0, 0), 0° on the top; all other 36 components are on the bottom. Coordinates are in millimetres with positive Y down and KiCad orientation degrees, applied after the bottom-side flip.

- Courtyard overlaps: 0; physical body overlaps: 0.
- Minimum pad-to-pad copper gap: 0.298285 mm (required 0.15 mm).
- Minimum copper-to-board-edge clearance: 0.305327 mm (required 0.30 mm).
- Maximum body radius: 6.609147 mm (board radius 6.75 mm).
- Maximum courtyard radius: 6.992833 mm (permitted up to 7.00 mm).
- Exact checks were repeated from the saved 8-decimal coordinates.

Candidate: `placement_candidate.json`; orientation geometry: `geometry.json`; exact audit: `placement_audit.json`.

This confirms placement geometry only. The candidate still needs net assignment, routing, and KiCad DRC before PCB/manufacturing promotion. Circuit values were not modified.

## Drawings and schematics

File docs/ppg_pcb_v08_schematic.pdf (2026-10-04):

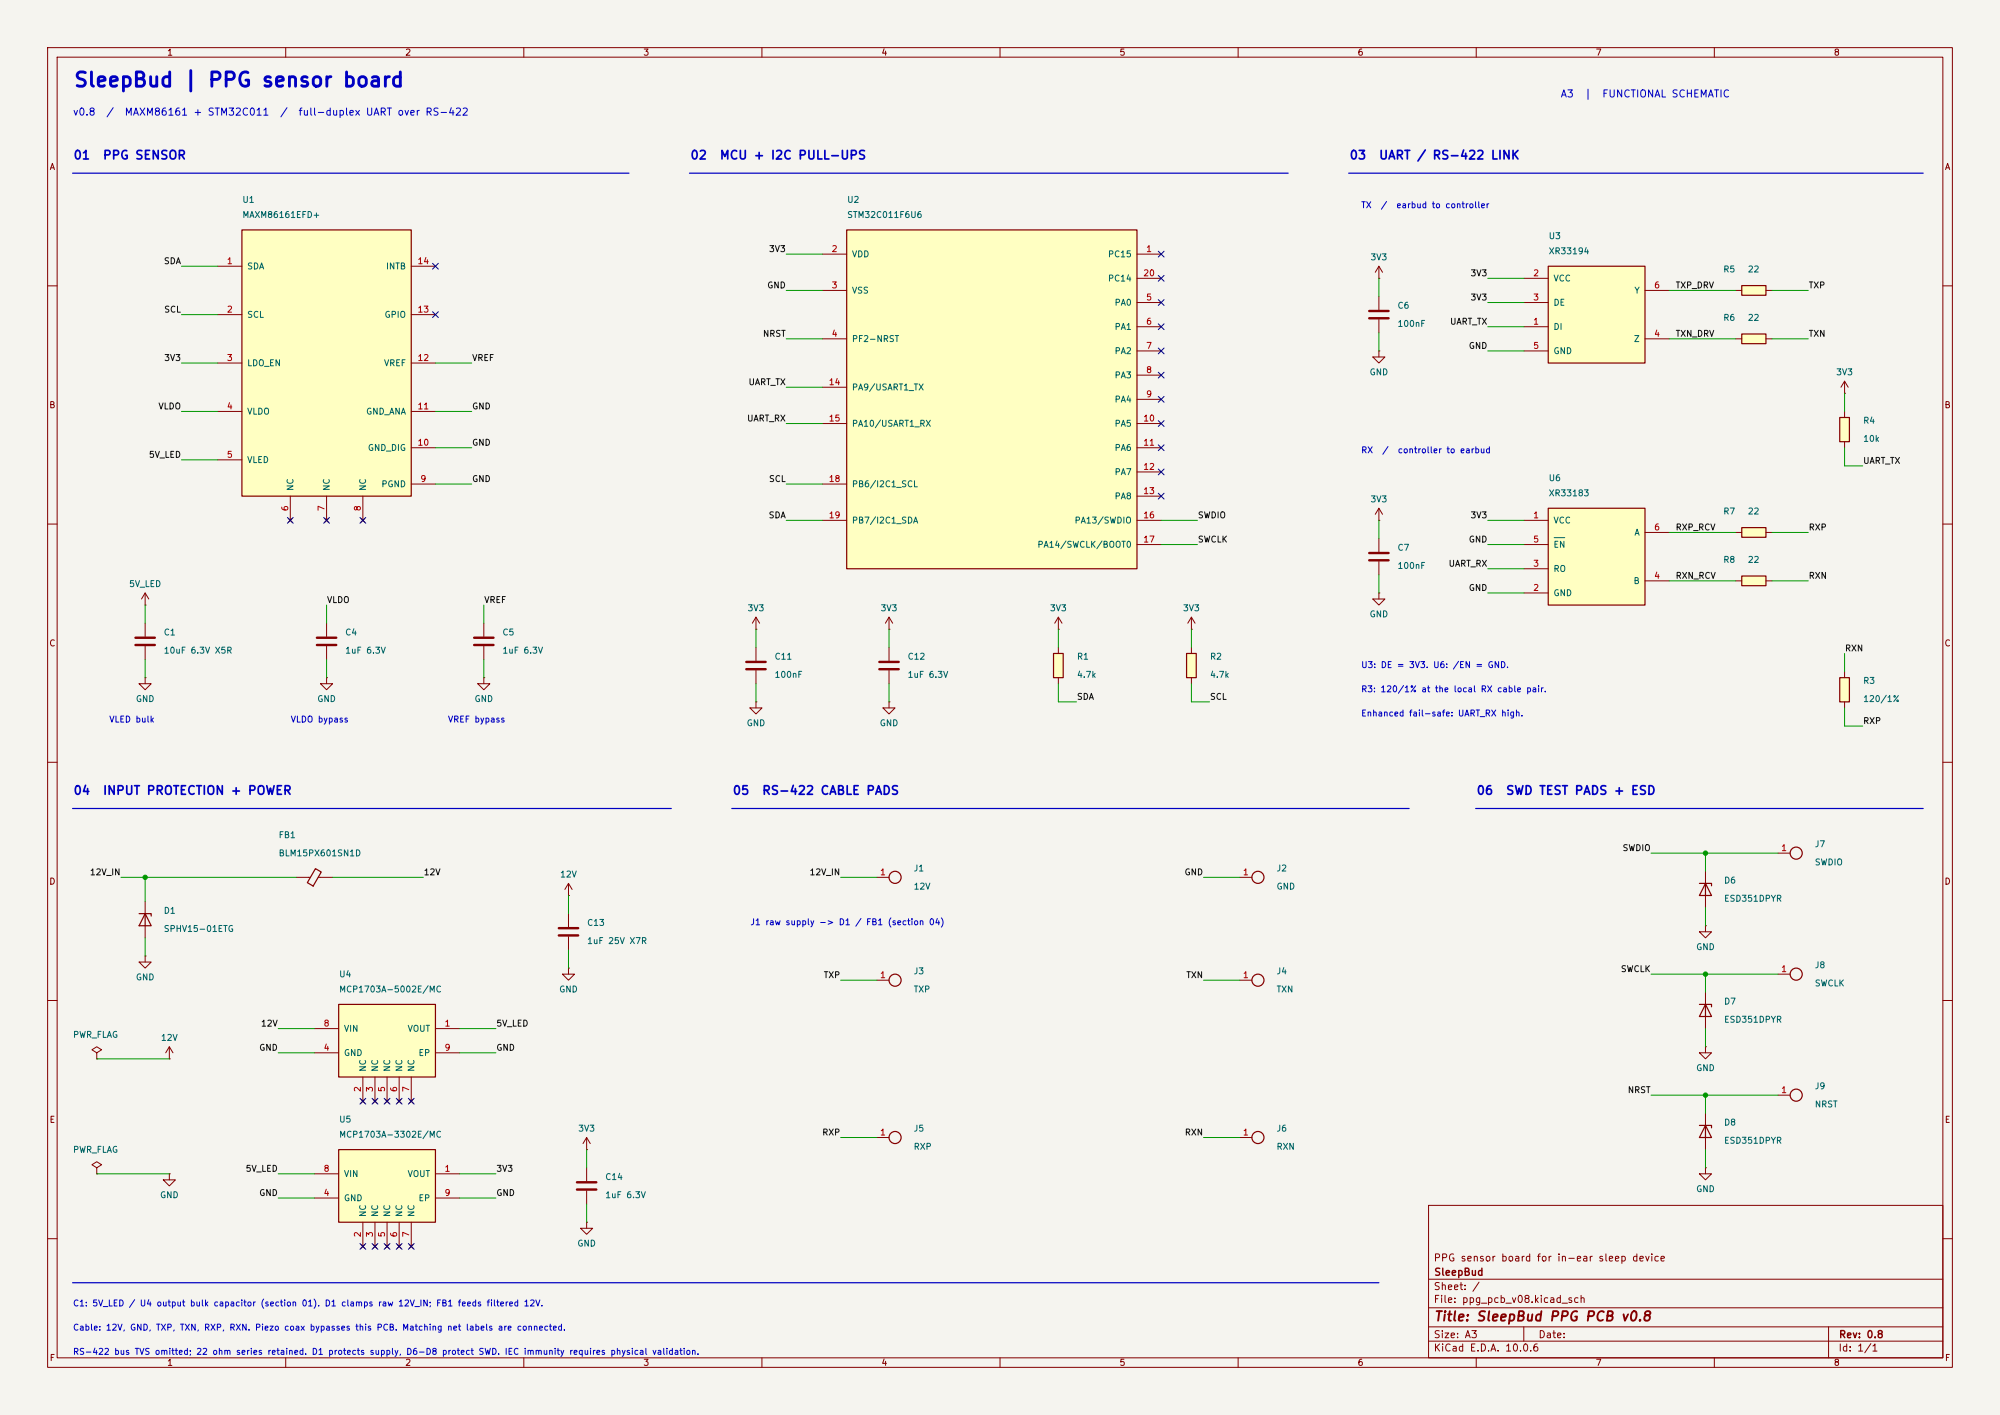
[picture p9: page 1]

SleepBud | PPG sensor board

v0.8 / MAXM86161 + STM32C011 / full-duplex UART over RS-422

U3: DE = 3V3. U6: /EN = GND. 02 MCU + I2C PULL-UPS

TX / earbud to controller

VREF 04 INPUT PROTECTION + POWER
VREF GND

Enhanced fail-safe: UART_RX high. R3: 120/1% at the local RX cable pair.

PPG sensor board for in-ear sleep device
SleepBud
Sheet: /
File: ppg_pcb_v08.kicad_sch
Title: SleepBud PPG PCB v0.8

C1: 5V_LED / U4 output bulk capacitor (section 01). D1 clamps raw 12V_IN; FB1 feeds filtered 12V.

Cable: 12V, GND, TXP, TXN, RXP, RXN. Piezo coax bypasses this PCB. Matching net labels are connected. RS-422 bus TVS omitted; 22 ohm series retained. D1 protects supply, D6-D8 protect SWD. IEC immunity requires physical validation.

Size: A3 | Rev: 0.8 | F Date:
KiCad E.D.A. 10.0.6 | Id: 1/1

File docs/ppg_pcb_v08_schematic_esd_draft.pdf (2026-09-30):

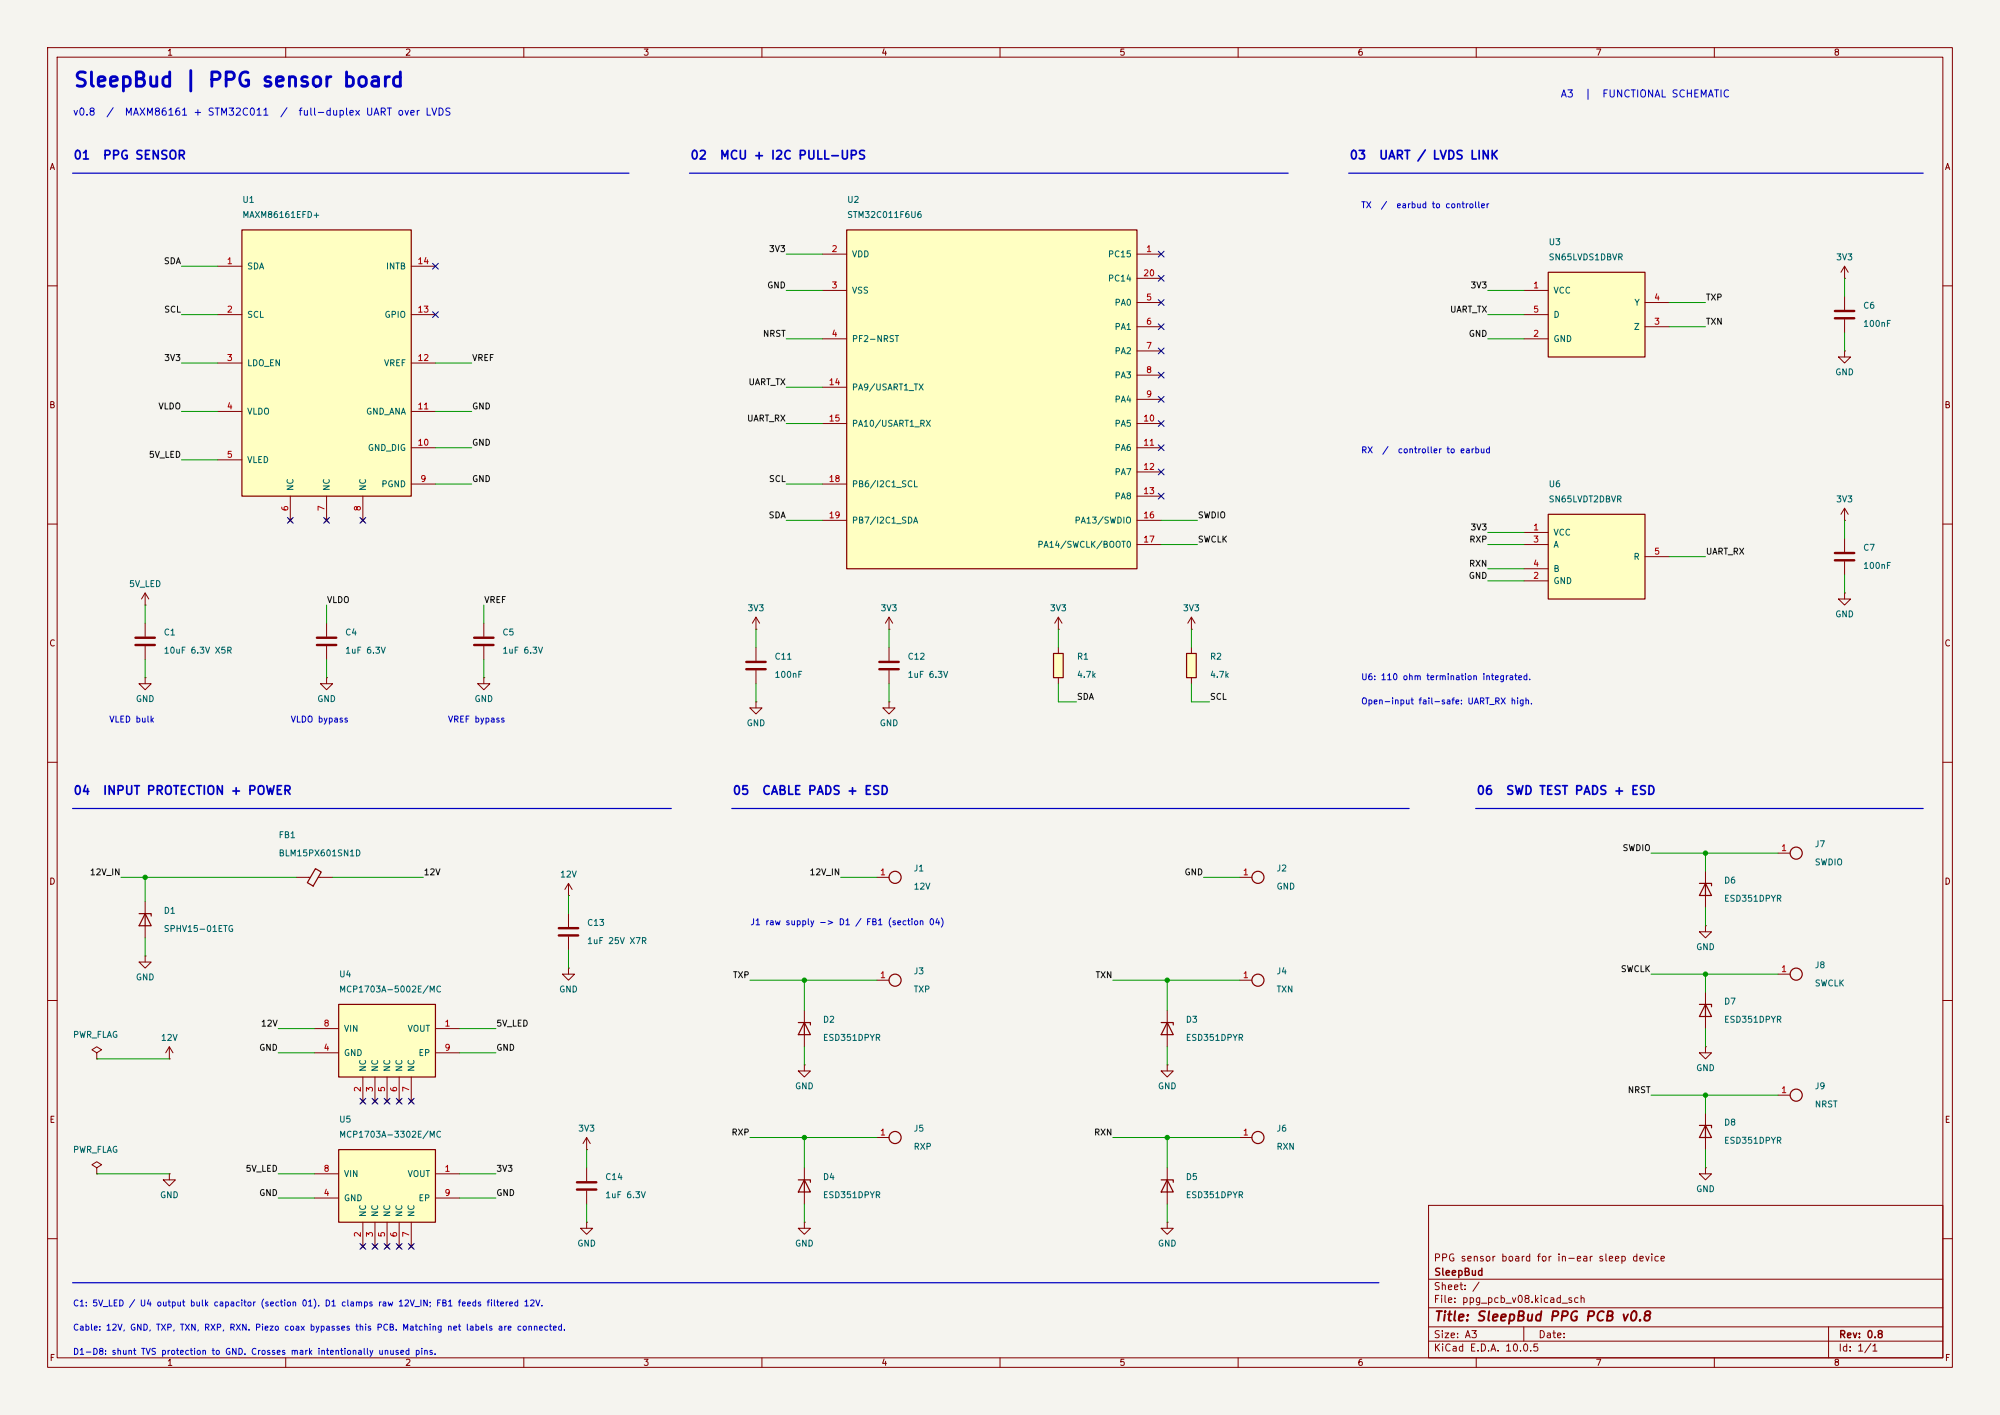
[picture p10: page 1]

SleepBud | PPG sensor board

v0.8 / MAXM86161 + STM32C011 / full-duplex UART over LVDS

RX / controller to earbud

Open-input fail-safe: UART_RX high.

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

C1: 5V_LED / U4 output bulk capacitor (section 01). D1 clamps raw 12V_IN; FB1 feeds filtered 12V. Cable: 12V, GND, TXP, TXN, RXP, RXN. Piezo coax bypasses this PCB. Matching net labels are connected. D1-D8: shunt TVS protection to GND. Crosses mark intentionally unused pins.

Size: A3 | Rev: 0.8 | F Date:
KiCad E.D.A. 10.0.5 | Id: 1/1

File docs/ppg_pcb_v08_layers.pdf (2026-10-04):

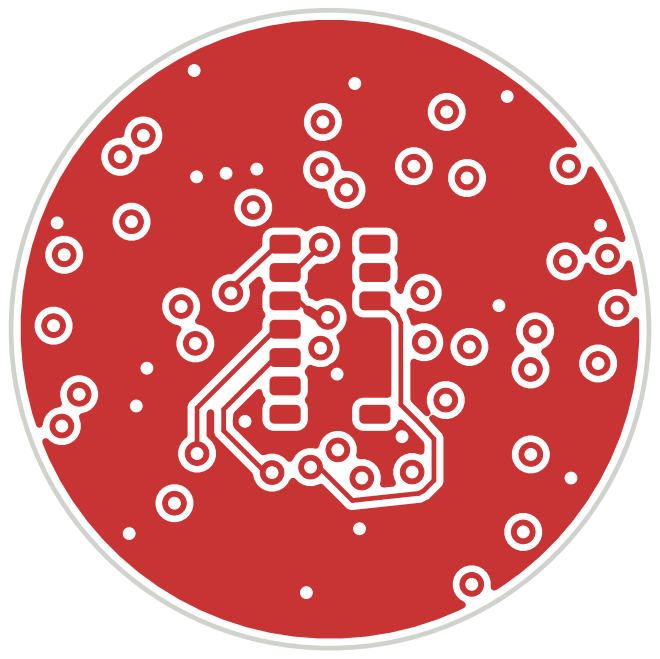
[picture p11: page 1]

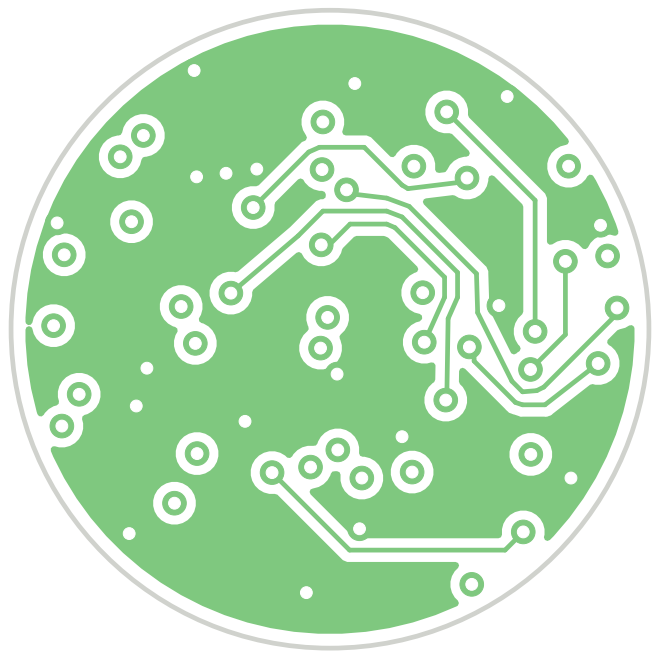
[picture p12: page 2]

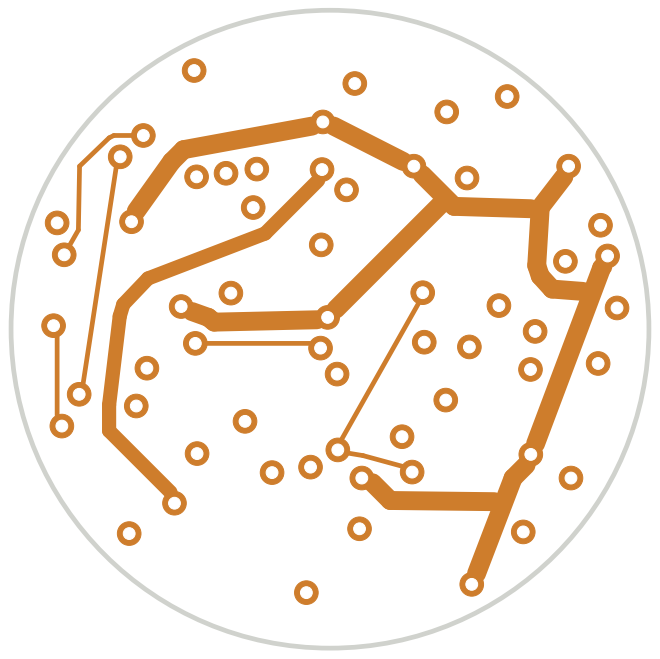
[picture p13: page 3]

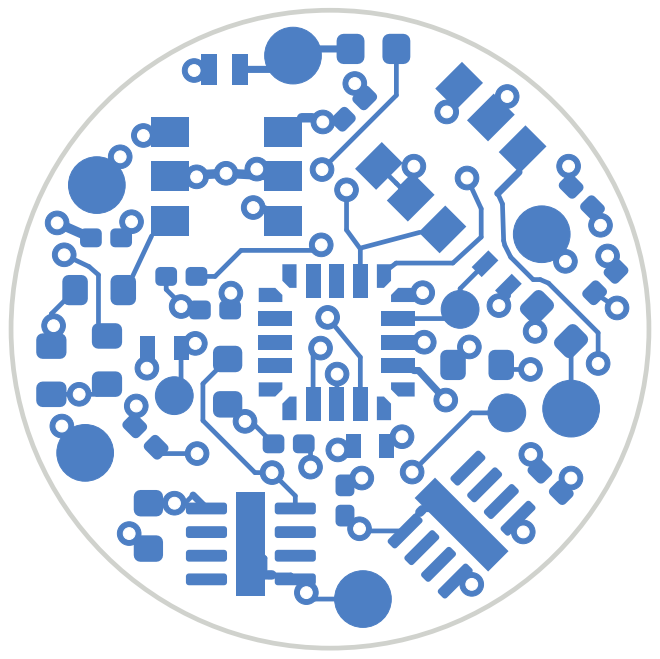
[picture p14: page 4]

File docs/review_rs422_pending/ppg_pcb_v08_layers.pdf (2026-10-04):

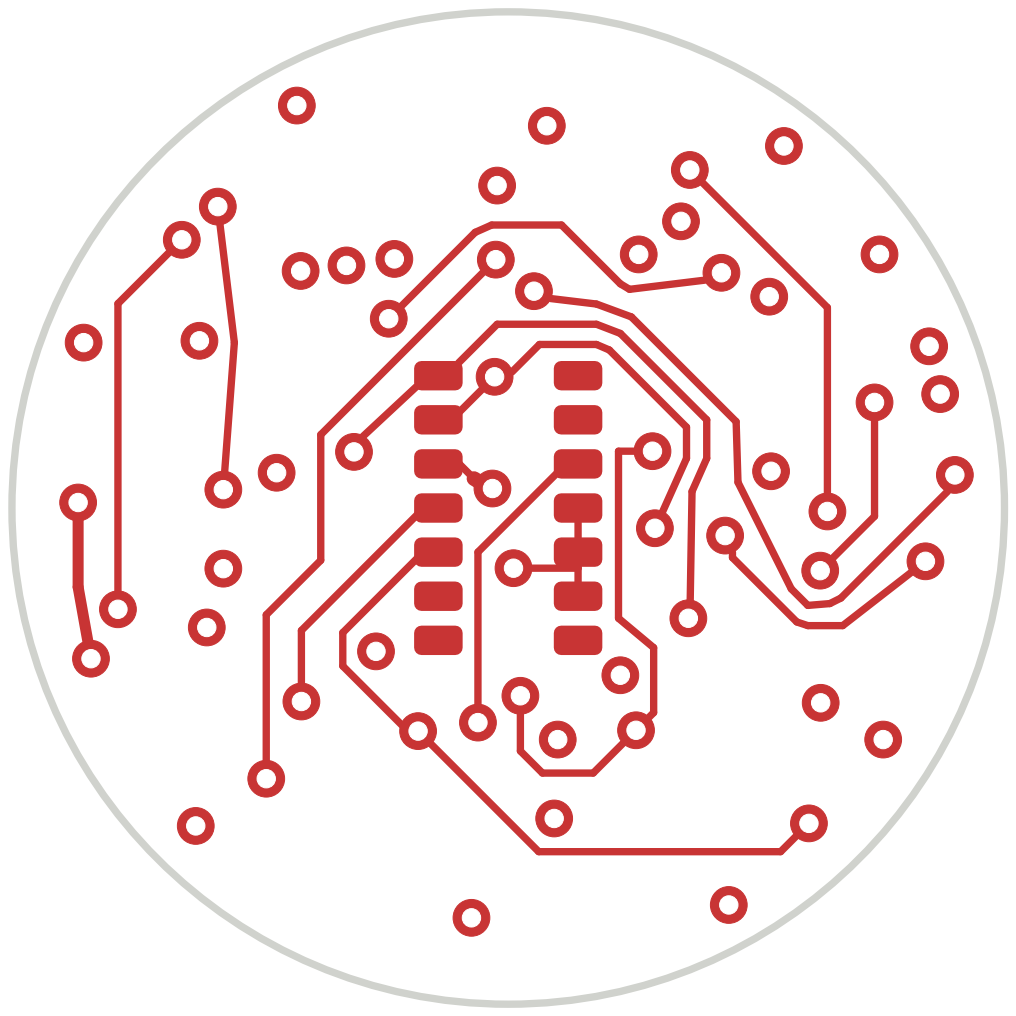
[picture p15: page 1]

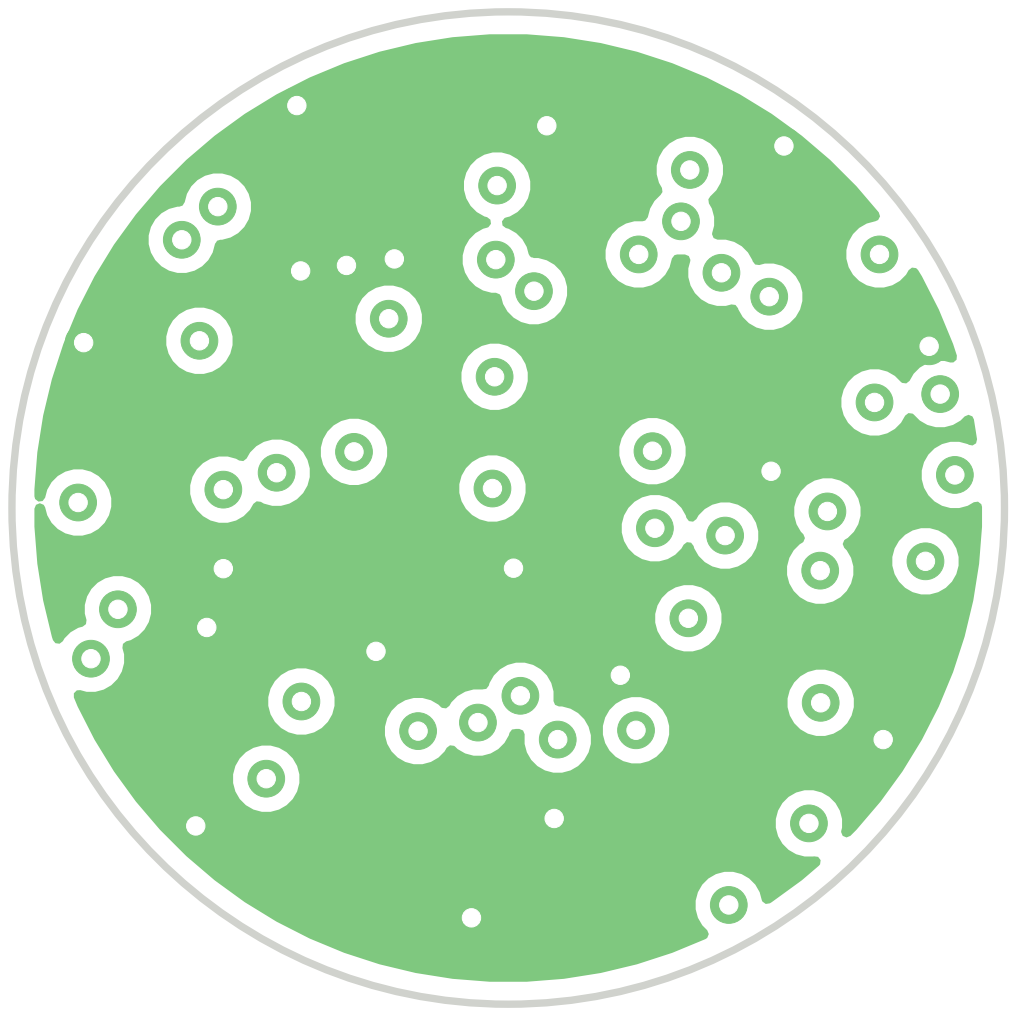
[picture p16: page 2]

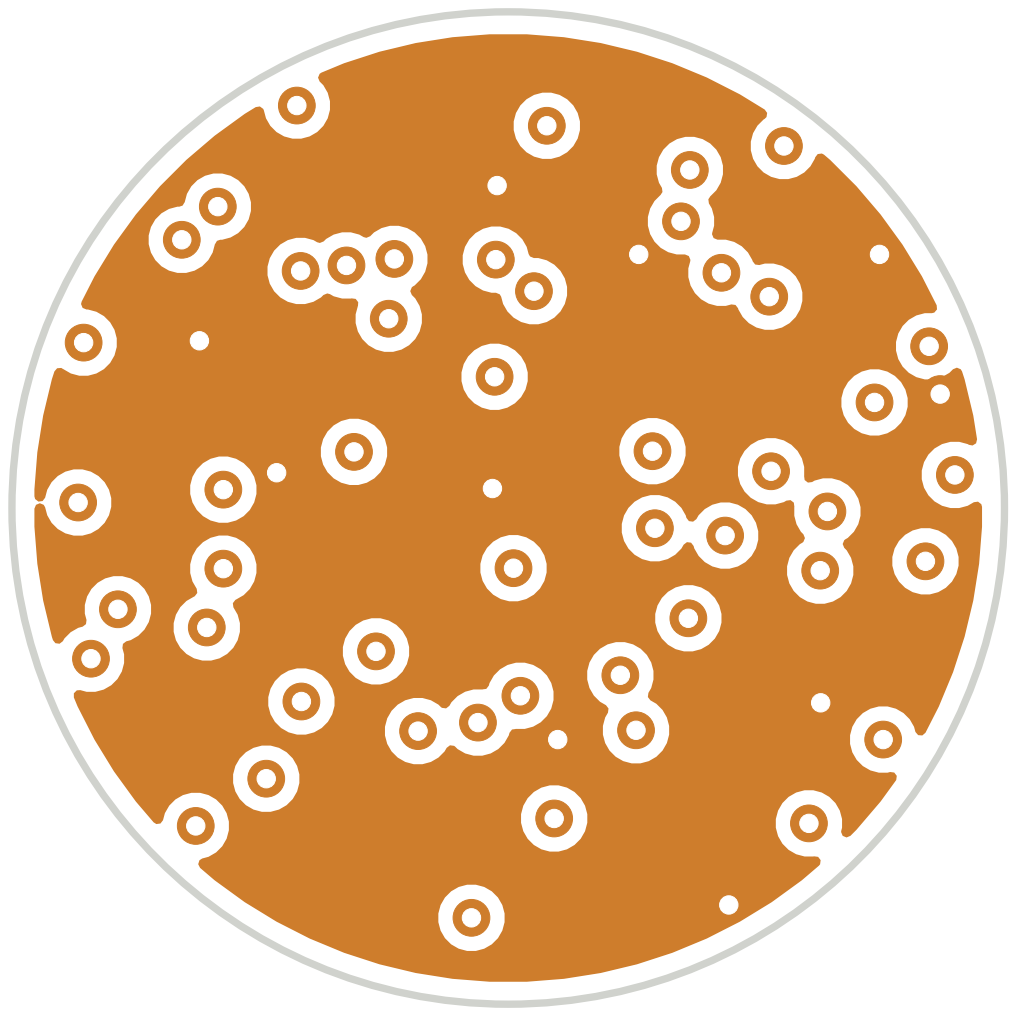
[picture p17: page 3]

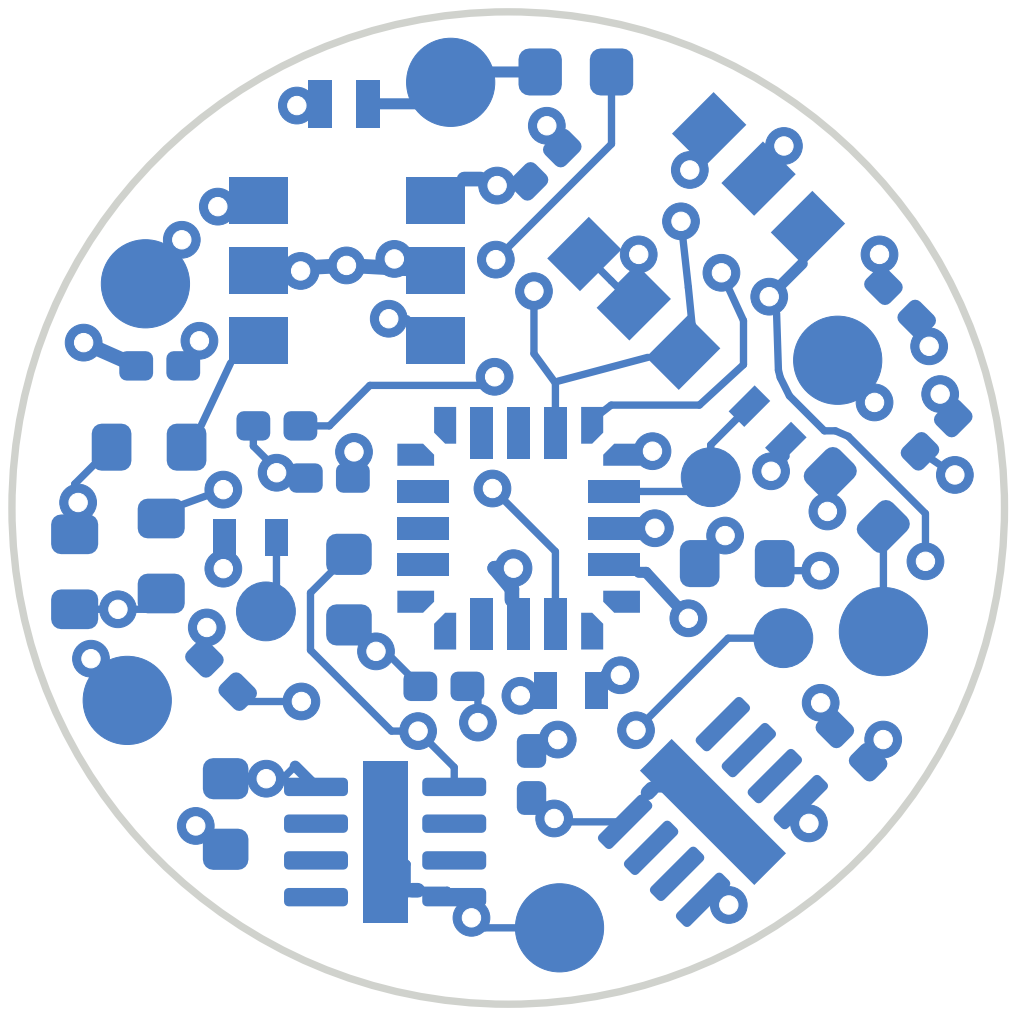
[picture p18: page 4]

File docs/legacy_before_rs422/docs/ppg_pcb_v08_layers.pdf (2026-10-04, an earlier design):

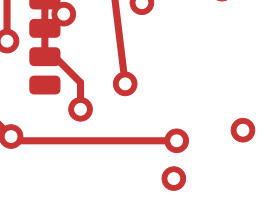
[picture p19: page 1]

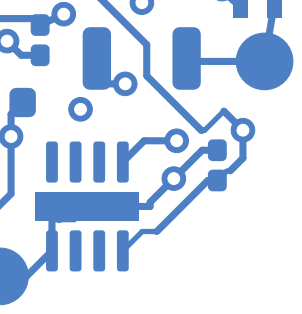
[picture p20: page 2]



U1


v0.8 PPG SleepBud SWDIO SWCLK

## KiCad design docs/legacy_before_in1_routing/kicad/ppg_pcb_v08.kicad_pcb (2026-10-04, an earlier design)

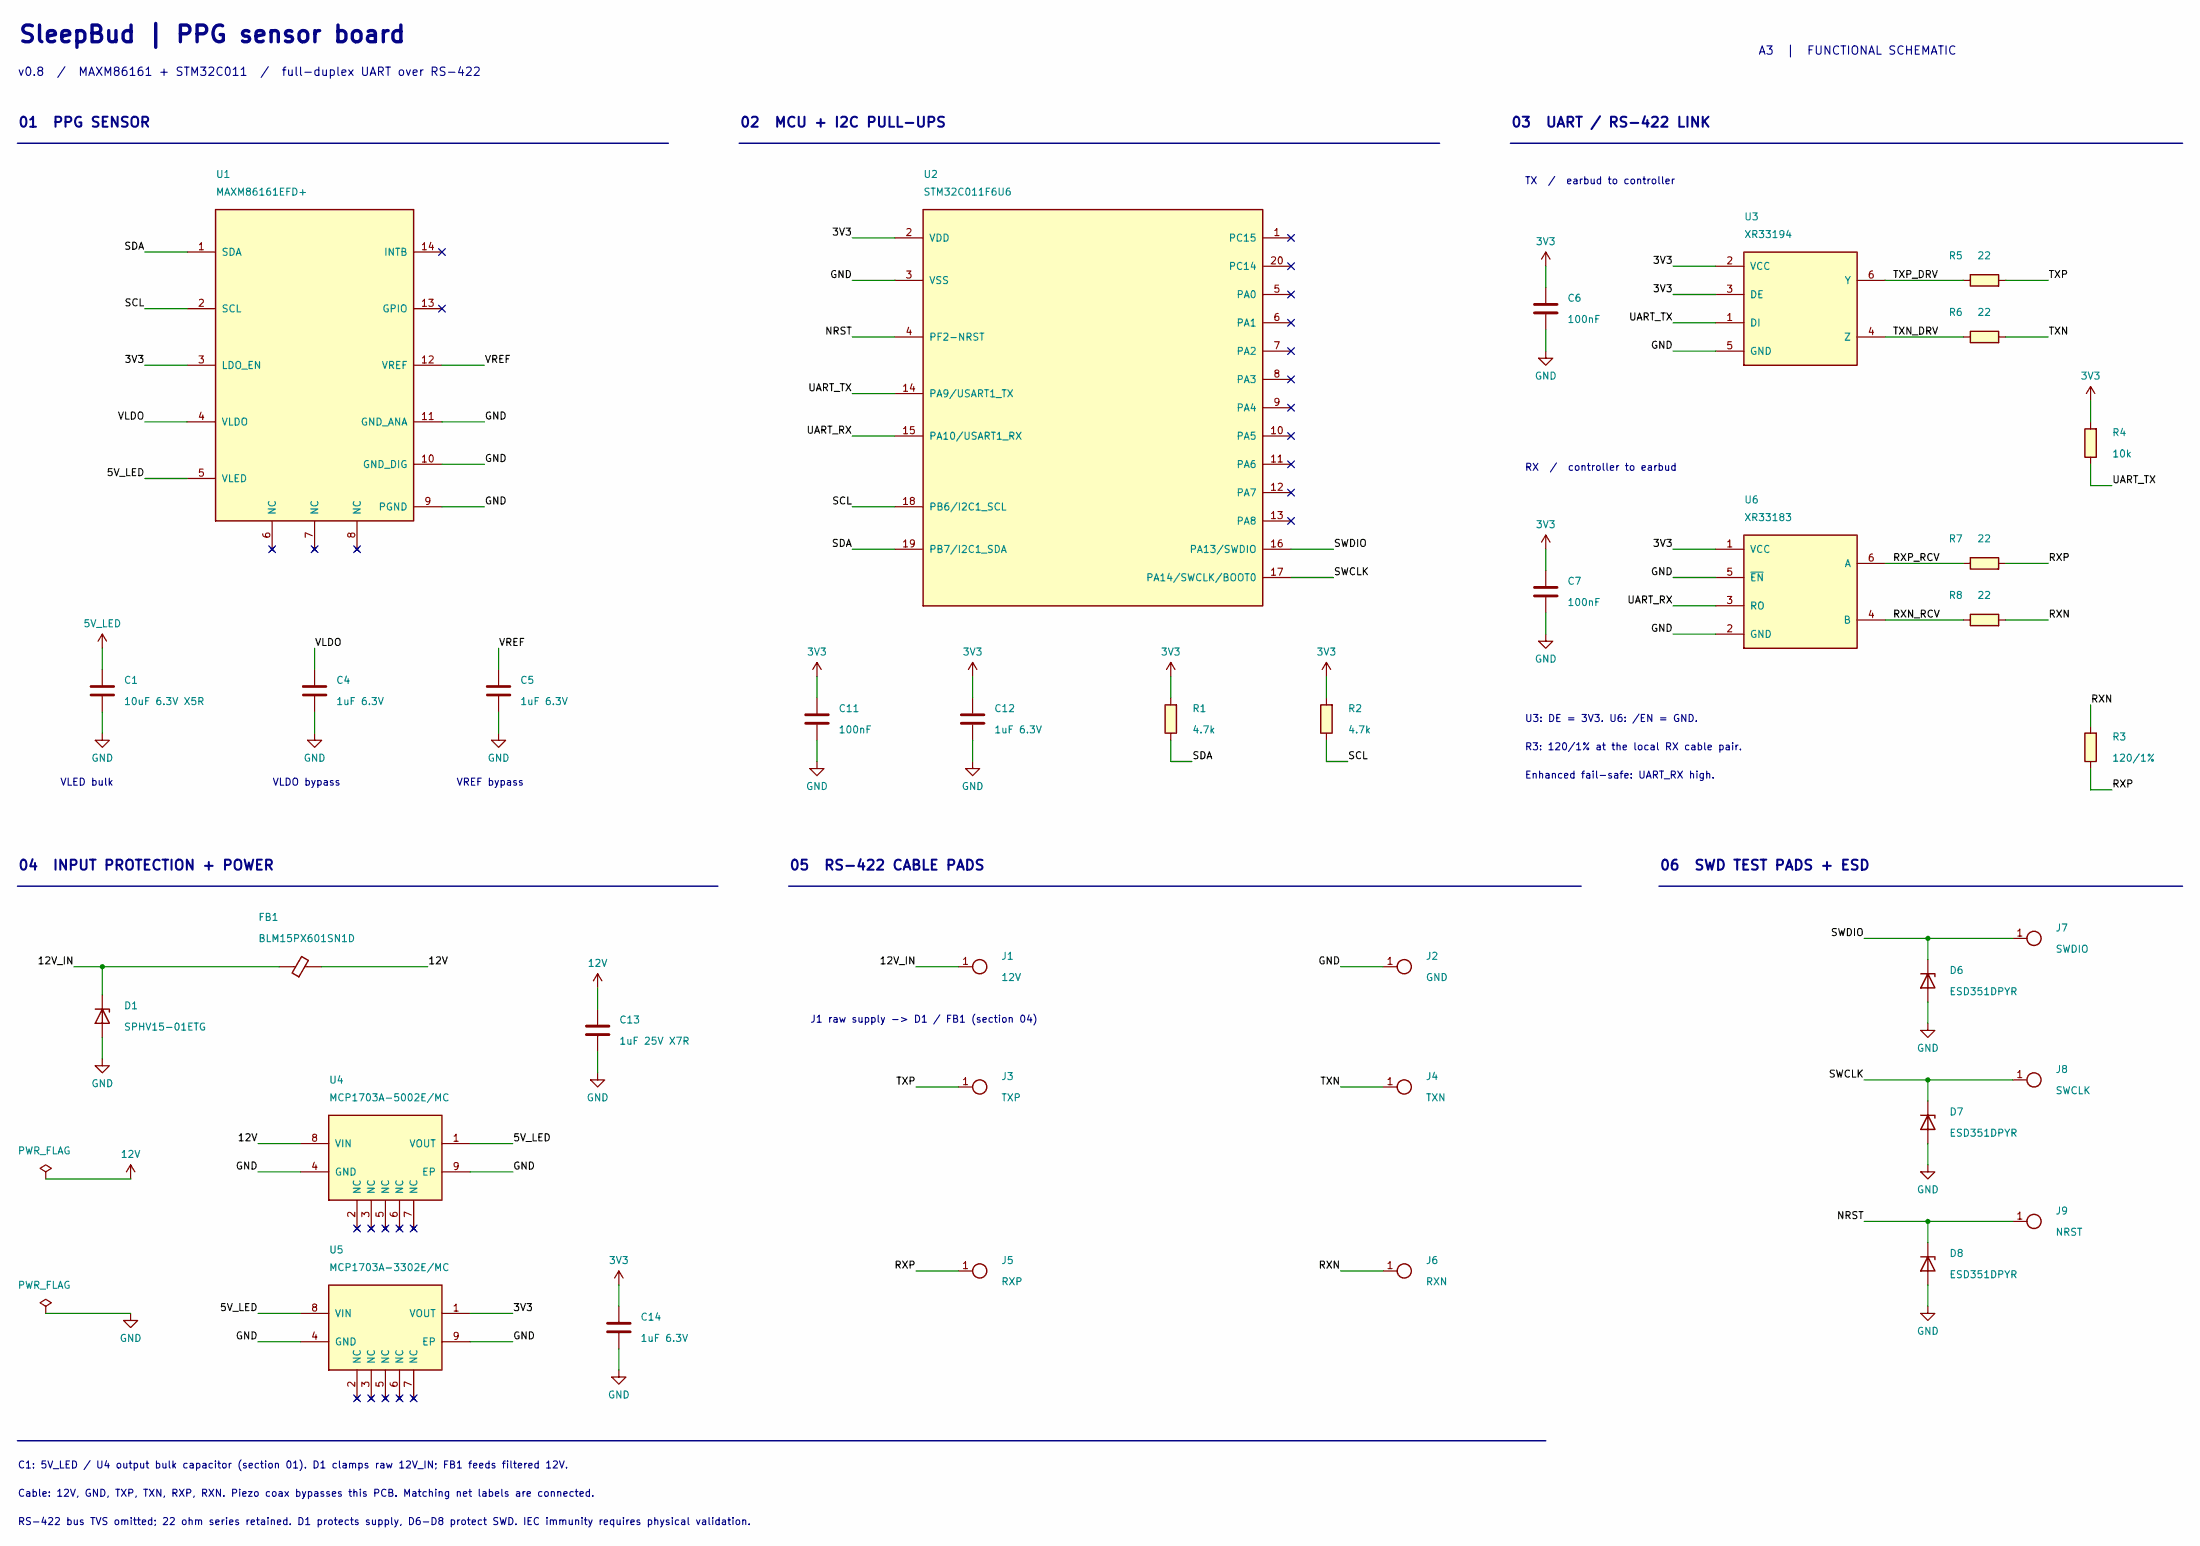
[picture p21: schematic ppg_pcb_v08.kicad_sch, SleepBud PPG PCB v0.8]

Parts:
C1: 10uF 6.3V X5R; C_0402_1005Metric
C4, C5, C12, C14: 1uF 6.3V; C_0201_0603Metric
C6, C7, C11: 100nF; C_0201_0603Metric
C13: 1uF 25V X7R; C_0402_1005Metric
D1: SPHV15-01ETG; TVS_SOD882_1x0.6; MPN SPHV15-01ETG
D6, D7, D8: ESD351DPYR; TI_DPY0002A_1x0.6; MPN ESD351DPYR
FB1: BLM15PX601SN1D; L_0402_1005Metric; MPN BLM15PX601SN1D
J1: 12V; CablePad_D1.2
J2: GND; CablePad_D1.2
J3: TXP; CablePad_D1.2
J4: TXN; CablePad_D1.2
J5: RXP; CablePad_D1.2
J6: RXN; CablePad_D1.2
J7: SWDIO; CablePad_D0.8
J8: SWCLK; CablePad_D0.8
J9: NRST; CablePad_D0.8
R1, R2: 4.7k; R_0201_0603Metric
R3: 120/1%; R_0402_1005Metric; MPN CRCW0402120RFKEDHP
R4: 10k; R_0201_0603Metric
R5, R6, R7, R8: 22; R_0402_1005Metric; MPN CRCW040222R0JNEDHP
U1: MAXM86161EFD+; MAXM86161_OLGA-14
U2: STM32C011F6U6; ST_UFQFPN-20_3x3mm_P0.5mm
U3: XR33194; TSOT23-6_MaxLinear; MPN XR33194ESBTR
U4: MCP1703A-5002E/MC; DFN-8-1EP_2x3mm_P0.5mm_EP0.61x2.2mm
U5: MCP1703A-3302E/MC; DFN-8-1EP_2x3mm_P0.5mm_EP0.61x2.2mm
U6: XR33183; TSOT23-6_MaxLinear; MPN XR33183ESBTR

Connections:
3V3: C6.1, C7.1, C11.1, C12.1, C14.1, R1.2, R2.2, R4.2, U1.3 (LDO_EN), U2.2 (VDD), U3.2 (VCC), U3.3 (DE), U5.1 (VOUT), U6.1 (VCC)
5V_LED: C1.1, U1.5 (VLED), U4.1 (VOUT), U5.8 (VIN)
12V: C13.1, FB1.2, U4.8 (VIN)
/12V_IN: D1.1 (K), FB1.1, J1.1
/NRST: D8.1 (IO/K), J9.1, U2.4 (PF2-NRST)
/RXN: J6.1, R3.2, R8.2
/RXN_RCV: R8.1, U6.4 (B)
/RXP: J5.1, R3.1, R7.2
/RXP_RCV: R7.1, U6.6 (A)
/SCL: R2.1, U1.2 (SCL), U2.18 (PB6/I2C1_SCL)
/SDA: R1.1, U1.1 (SDA), U2.19 (PB7/I2C1_SDA)
/SWCLK: D7.1 (IO/K), J8.1, U2.17 (PA14/SWCLK/BOOT0)
/SWDIO: D6.1 (IO/K), J7.1, U2.16 (PA13/SWDIO)
/TXN: J4.1, R6.2
/TXN_DRV: R6.1, U3.4 (Z)
/TXP: J3.1, R5.2
/TXP_DRV: R5.1, U3.6 (Y)
/UART_RX: U2.15 (PA10/USART1_RX), U6.3 (RO)
/UART_TX: R4.1, U2.14 (PA9/USART1_TX), U3.1 (DI)
/VLDO: C4.1, U1.4 (VLDO)
/VREF: C5.1, U1.12 (VREF)
GND: C1.2, C4.2, C5.2, C6.2, C7.2, C11.2, C12.2, C13.2, C14.2, D1.2 (A), D6.2 (GND/A), D7.2 (GND/A), D8.2 (GND/A), J2.1, U1.9 (PGND), U1.10 (GND_DIG), U1.11 (GND_ANA), U2.3 (VSS), U3.5 (GND), U4.4 (GND), U4.9 (EP), U5.4 (GND), U5.9 (EP), U6.2 (GND), U6.5 (~EN)

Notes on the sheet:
SleepBud | PPG sensor board
v0.8 / MAXM86161 + STM32C011 / full-duplex UART over RS-422
A3 | FUNCTIONAL SCHEMATIC
01 PPG SENSOR
02 MCU + I2C PULL-UPS
03 UART / RS-422 LINK
VLED bulk
VLDO bypass
VREF bypass
TX / earbud to controller
RX / controller to earbud
U3: DE = 3V3. U6: /EN = GND.
R3: 120/1% at the local RX cable pair.
Enhanced fail-safe: UART_RX high.
04 INPUT PROTECTION + POWER
05 RS-422 CABLE PADS
J1 raw supply -> D1 / FB1 (section 04)
06 SWD TEST PADS + ESD
C1: 5V_LED / U4 output bulk capacitor (section 01). D1 clamps raw 12V_IN; FB1 feeds filtered 12V.
Cable: 12V, GND, TXP, TXN, RXP, RXN. Piezo coax bypasses this PCB. Matching net labels are connected.
RS-422 bus TVS omitted; 22 ohm series retained. D1 protects supply, D6-D8 protect SWD. IEC immunity requires physical validation.

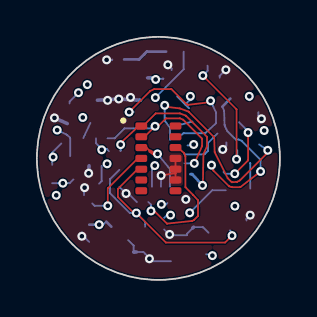
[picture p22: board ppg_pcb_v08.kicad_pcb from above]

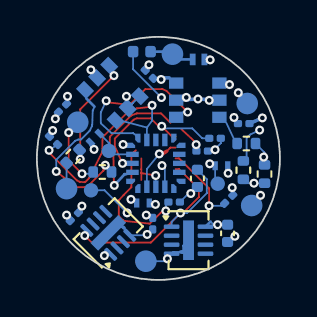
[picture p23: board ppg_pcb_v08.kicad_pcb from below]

Board: 4 copper layers, 13.5 x 13.5 mm, 37 parts (36 on the bottom side), 22 nets.

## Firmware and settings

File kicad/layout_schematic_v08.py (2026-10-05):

"""Readable A3 schematic layout; preserve existing component/pin UUIDs.

Run: python layout_schematic_v08.py [input.kicad_sch] [output.kicad_sch]
Only presentation is changed. Net membership is checked separately with KiCad.
"""
from pathlib import Path
from copy import deepcopy
from collections import defaultdict
import json
import re
import sys
import uuid
import design_v08 as D


class Quoted(str):
    pass


def parse(source):
    tokens = re.findall(r'"(?:\\.|[^"\\])*"|[()]|[^\s()]+', source)
    stack, root = [], None
    for token in tokens:
        if token == '(':
            node = []
            if stack:
                stack[-1].append(node)
            else:
                root = node
            stack.append(node)
        elif token == ')':
            stack.pop()
        else:
            if token.startswith('"'):
                token = Quoted(json.loads(token))
            stack[-1].append(token)
    assert not stack
    return root


def dump(node):
    if isinstance(node, list):
        return '(' + ' '.join(dump(v) for v in node) + ')'
    if isinstance(node, Quoted):
        return json.dumps(node, ensure_ascii=False)
    if isinstance(node, float):
        return f'{node:.4f}'.rstrip('0').rstrip('.')
    return str(node)


def children(node, key):
    return [v for v in node[1:] if isinstance(v, list) and v[0] == key]


def get(node, key):
    return next(v for v in node[1:] if isinstance(v, list) and v[0] == key)


def prop(node, name):
    return next(v for v in children(node, 'property') if v[1] == name)


def uid():
    return ['uuid', Quoted(str(uuid.uuid4()))]


def effects(size=1.27, justify=None, bold=False):
    font = ['font', ['size', size, size]]
    if bold:
        font.append(['bold', 'yes'])
    result = ['effects', font]
    if justify:
        result.append(['justify', *justify.split()])
    return result


def tidy(source, target):
    sch = parse(source.read_text(encoding='utf-8'))
    get(sch, 'paper')[1] = Quoted('A3')
    original = {str(prop(s, 'Reference')[2]): deepcopy(s) for s in children(sch, 'symbol')}
    library = get(sch, 'lib_symbols')
    libs = {str(s[1]): s for s in children(library, 'symbol')}
    power_pool = defaultdict(list)
    for ref, symbol in original.items():
        if ref.startswith('#'):
            power_pool[str(get(symbol, 'lib_id')[1])].append(symbol)
    power_templates = {name: deepcopy(pool[0]) for name, pool in power_pool.items()}
    used_refs = set(original)

    def auxiliary_symbol(libid):
        """Reuse identities where possible; grow the power-symbol pool safely."""
        if power_pool[libid]:
            return power_pool[libid].pop(0)
        symbol = deepcopy(power_templates[libid])
        prefix = '#FLG' if libid.endswith(':PWR_FLAG') else '#PWR'
        index = 1
        while f'{prefix}{index:03d}' in used_refs:
            index += 1
        ref = f'{prefix}{index:03d}'
        used_refs.add(ref)

        def renew(node):
            if node[0] == 'uuid':
                node[1] = Quoted(str(uuid.uuid4()))
            elif node[0] == 'reference':
                node[1] = Quoted(ref)
            for child in node[1:]:
                if isinstance(child, list):
                    renew(child)
        renew(symbol)
        prop(symbol, 'Reference')[2] = Quoted(ref)
        return symbol

    # Power symbols have zero-length pins: the pin names/numbers must be hidden
    # at symbol level, otherwise KiCad renders a duplicate vertical net name.
    for name in ['GND', '3V3', '5V_LED', '12V', 'PWR_FLAG']:
        lib = libs['SleepBud:' + name]
        lib[:] = [v for v in lib if not (isinstance(v, list) and v[0] in ('pin_names', 'pin_numbers'))]
        lib.extend([['pin_names', ['offset', 0], ['hide', 'yes']], ['pin_numbers', ['hide', 'yes']]])

    def reshape(name, w, h, pin_positions):
        lib = libs['SleepBud:' + name]
        for unit in children(lib, 'symbol'):
            for rect in children(unit, 'rectangle'):
                get(rect, 'start')[1:] = [-w, -h]
                get(rect, 'end')[1:] = [w, h]
            for pin in children(unit, 'pin'):
                num = str(get(pin, 'number')[1])
                get(pin, 'at')[1:] = pin_positions[num]

    u1_positions = {}
    for n, y in [('1', 20.32), ('2', 10.16), ('3', 0), ('4', -10.16), ('5', -20.32)]:
        u1_positions[n] = [-22.86, y, 0]
    for n, y in [('14', 20.32), ('13', 10.16), ('12', 0), ('11', -10.16), ('10', -17.78), ('9', -25.4)]:
        u1_positions[n] = [22.86, y, 180]
    for n, x in [('6', -7.62), ('7', 0), ('8', 7.62)]:
        u1_positions[n] = [x, -33.02, 90]
    reshape('MAXM86161', 17.78, 27.94, u1_positions)

    u2_positions = {}
    for n, y in [('2', 30.48), ('3', 22.86), ('4', 12.7), ('14', 2.54), ('15', -5.08), ('18', -17.78), ('19', -25.4)]:
        u2_positions[n] = [-35.56, y, 0]
    for i, n in enumerate(['1', '20', '5', '6', '7', '8', '9', '10', '11', '12', '13', '16', '17']):
        u2_positions[n] = [35.56, 30.48 - i * 5.08, 180]
    reshape('STM32C011F6U6', 30.48, 35.56, u2_positions)

    # Regenerate only graphical placement and wires; keep all main identities.
    sch[:] = [v for v in sch if not (isinstance(v, list) and v[0] in
             ('symbol', 'wire', 'label', 'global_label', 'junction', 'no_connect', 'text', 'polyline', 'rectangle'))]
    items = []

    def wire(x1, y1, x2, y2):
        items.append(['wire', ['pts', ['xy', x1, y1], ['xy', x2, y2]], ['stroke', ['width', 0], ['type', 'default']], uid()])

    def junction(x, y):
        items.append(['junction', ['at', x, y], ['diameter', 0], ['color', 0, 0, 0, 0], uid()])

    def label(net, x, y, left=False):
        items.append(['label', Quoted(net), ['at', x, y, 180 if left else 0],
                      effects(1.27, 'right bottom' if left else 'left bottom'), uid()])

    def text(value, x, y, size=1.27, bold=False):
        items.append(['text', Quoted(value), ['exclude_from_sim', 'no'], ['at', x, y, 0], effects(size, 'left top', bold), uid()])

    def rule(x1, y, x2):
        items.append(['polyline', ['pts', ['xy', x1, y], ['xy', x2, y]],
                      ['stroke', ['width', 0.254], ['type', 'default']], ['fill', ['type', 'none']], uid()])

    def heading(title, x, y, width):
        text(title, x, y, 1.8, True)
        rule(x, y + 4.6, x + width)

    def move(symbol, x, y, rotation=0, ref_at=None, val_at=None):
        symbol = deepcopy(symbol)
        get(symbol, 'at')[1:] = [x, y, rotation]
        for field in children(symbol, 'property'):
            get(field, 'at')[1:] = [x, y, 0]
        for name, pos in [('Reference', ref_at), ('Value', val_at)]:
            if pos is not None:
                field = prop(symbol, name)
                get(field, 'at')[1:] = [*pos, 0]
                field[:] = [v for v in field if not (isinstance(v, list) and v[0] == 'effects')]
                field.append(effects(1.27, 'left'))
        items.append(symbol)
        return symbol

    def power(net, x, y):
        symbol = auxiliary_symbol('SleepBud:' + net)
        result = move(symbol, x, y)
        field = prop(result, 'Value')
        get(field, 'at')[1:] = [x, y + (4.445 if net == 'GND' else -4.445), 0]
        field[:] = [v for v in field if not (isinstance(v, list) and v[0] == 'effects')]
        field.append(effects())

    def ic(ref, x, y):
        src = original[ref]
        lib = libs[str(get(src, 'lib_id')[1])]
        rect = next(r for u in children(lib, 'symbol') for r in children(u, 'rectangle'))
        w, h = map(float, get(rect, 'end')[1:])
        move(src, x, y, ref_at=(x-w, y-h-6.35), val_at=(x-w, y-h-3.175))
        for unit in children(lib, 'symbol'):
            for p in children(unit, 'pin'):
                num = str(get(p, 'number')[1])
                px, py, angle = map(float, get(p, 'at')[1:])
                ax, ay = x+px, y-py
                net = D.COMPONENTS[ref]['pins'][num]
                if net is None:
                    items.append(['no_connect', ['at', ax, ay], uid()])
                elif angle == 0:
                    wire(ax, ay, ax-7.62, ay)
                    label(net, ax-7.62, ay, True)
                elif angle == 180:
                    if ref in ('U3', 'U6') and num in ('4', '6') and 'R5' in original:
                        series = {('U3', '6'): 'R5', ('U3', '4'): 'R6', ('U6', '6'): 'R7', ('U6', '4'): 'R8'}[ref, num]
                        sx = 368.3
                        placed = move(original[series], sx, ay, 90,
                                      ref_at=(sx-3.81, ay-4.445), val_at=(sx+1.27, ay-4.445))
                        for field_name in ('Reference', 'Value'):
                            get(prop(placed, field_name), 'at')[3] = 90
                        wire(ax, ay, sx-3.81, ay)
                        label(net, ax+1.27, ay)
                        wire(sx+3.81, ay, sx+11.43, ay)
                        label(D.COMPONENTS[series]['pins']['2'], sx+11.43, ay)
                    else:
                        wire(ax, ay, ax+7.62, ay)
                        label(net, ax+7.62, ay)
                else:
                    raise ValueError('Unexpected connected bottom pin')

    def passive(ref, x, y):
        resistor = ref.startswith('R')
        # Rotate pull-ups 180 deg so pin 2 (3V3) faces upward, keeping pin/net IDs.
        placed = move(original[ref], x, y, 180 if resistor else 0,
                      ref_at=(x+3.81, y-1.905), val_at=(x+3.81, y+1.905))
        if resistor:
            # KiCad reverses field justification on a 180-degree symbol.
            for name in ['Reference', 'Value']:
                get(get(prop(placed, name), 'effects'), 'justify')[1:] = ['right']
        for num, dy in ([('2', -1), ('1', 1)] if resistor else [('1', -1), ('2', 1)]):
            net = D.COMPONENTS[ref]['pins'][num]
            py, ey = y + dy*3.81, y + dy*7.62
            wire(x, py, x, ey)
            if net in ['3V3', '5V_LED', '12V', 'GND']:
                power(net, x, ey)
            elif dy > 0:
                wire(x, ey, x+3.81, ey)
                label(net, x+3.81, ey)
            else:
                label(net, x, ey)

    def tvs(ref, x, y, rail_y=None):
        move(original[ref], x, y, ref_at=(x+3.81, y-1.905), val_at=(x+3.81, y+1.905))
        upper = y-7.62 if rail_y is None else rail_y
        wire(x, y-3.81, x, upper)
        if rail_y is None:
            label(D.COMPONENTS[ref]['pins']['1'], x, upper)
        else:
            junction(x, upper)
        wire(x, y+3.81, x, y+7.62)
        power(D.COMPONENTS[ref]['pins']['2'], x, y+7.62)

    def pad(ref, x, y, protection=None, drop=10.16):
        move(original[ref], x, y, ref_at=(x+3.81, y-1.905), val_at=(x+3.81, y+1.905))
        endpoint = x-(30.48 if protection else 11.43)
        wire(x-3.81, y, endpoint, y)
        label(D.COMPONENTS[ref]['pins']['1'], endpoint, y, True)
        if protection:
            assert D.COMPONENTS[ref]['pins']['1'] == D.COMPONENTS[protection]['pins']['1']
            tvs(protection, x-19.05, y+drop, rail_y=y)

    text('SleepBud | PPG sensor board', 15.24, 15.24, 3.0, True)
    text('v0.8  /  MAXM86161 + STM32C011  /  full-duplex UART over RS-422', 15.24, 22.86, 1.5)
    text('A3  |  FUNCTIONAL SCHEMATIC', 327.66, 19.05, 1.5)

    heading('01  PPG SENSOR', 15.24, 31.75, 116.84)
    heading('02  MCU + I2C PULL-UPS', 144.78, 31.75, 125.73)
    heading('03  UART / RS-422 LINK', 283.21, 31.75, 120.65)

    ic('U1', 68.58, 76.2)
    passive('C1', 30.48, 134.62)
    passive('C4', 68.58, 134.62)
    passive('C5', 101.6, 134.62)
    text('VLED bulk', 22.86, 150.495)
    text('VLDO bypass', 60.96, 150.495)
    text('VREF bypass', 93.98, 150.495)

    ic('U2', 208.28, 83.82)
    passive('C11', 158.75, 139.7)
    passive('C12', 186.69, 139.7)
    passive('R1', 222.25, 139.7)
    passive('R2', 250.19, 139.7)

    text('TX  /  earbud to controller', 285.75, 42.545)
    ic('U3', 335.28, 66.04)
    passive('C6', 289.56, 66.04)
    passive('R4', 387.35, 90.17)
    text('RX  /  controller to earbud', 285.75, 93.98)
    ic('U6', 335.28, 116.84)
    passive('C7', 289.56, 116.84)
    passive('R3', 387.35, 144.78)
    text('U3: DE = 3V3. U6: /EN = GND.', 285.75, 139.065)
    text('R3: 120/1% at the local RX cable pair.', 285.75, 144.145)
    text('Enhanced fail-safe: UART_RX high.', 285.75, 149.225)

    protected = 'FB1' in original
    if protected:
        required = {'D1', 'D6', 'D7', 'D8'}
        assert required.issubset(original), 'Protection layout requires supply and SWD TVS'
        heading('04  INPUT PROTECTION + POWER', 15.24, 165.1, 125.73)

        # The raw pad rail is visibly clamped before the series ferrite bead.
        # Existing 12V remains the filtered rail feeding C13 and U4.
        bead_x, rail_y = 66.04, 184.15
        move(original['FB1'], bead_x, rail_y,
             ref_at=(bead_x-7.62, rail_y-8.89), val_at=(bead_x-7.62, rail_y-5.08))
        wire(25.4, rail_y, bead_x-3.81, rail_y)
        label(D.COMPONENTS['FB1']['pins']['1'], 25.4, rail_y, True)
        wire(bead_x+3.81, rail_y, 88.9, rail_y)
        label(D.COMPONENTS['FB1']['pins']['2'], 88.9, rail_y)
        assert D.COMPONENTS['D1']['pins']['1'] == D.COMPONENTS['FB1']['pins']['1']
        tvs('D1', 30.48, 193.04, rail_y=rail_y)
        passive('C13', 119.38, 195.58)
        ic('U4', 81.28, 218.44)
        ic('U5', 81.28, 248.92)
        passive('C14', 123.19, 248.92)

        # A filtered-rail flag is needed because ERC does not propagate power
        # drive through a passive ferrite bead. Keep ground driven as before.
        for net, y in [('12V', 222.25), ('GND', 246.38)]:
            x = 20.32
            flag = auxiliary_symbol('SleepBud:PWR_FLAG')
            move(flag, x, y, val_at=(x-5.08, y-5.08))
            wire(x, y, x+15.24, y)
            power(net, x+15.24, y)

        heading('05  RS-422 CABLE PADS', 153.67, 165.1, 142.24)
        pad('J1', 187.96, 184.15)
        pad('J2', 264.16, 184.15)
        text('J1 raw supply -> D1 / FB1 (section 04)', 157.48, 193.04)
        for ref, x, y in [('J3', 187.96, 205.74), ('J4', 264.16, 205.74),
                          ('J5', 187.96, 226.06), ('J6', 264.16, 226.06)]:
            pad(ref, x, y)

        # Local 3V3 bypass additions use the open space below the cable pads.
        if {'C15', 'C16'}.issubset(original):
            text('Additional 3V3 bypass  /  0603 MLCC', 157.48, 234.95)
            passive('C15', 180.34, 251.46)
            passive('C16', 243.84, 251.46)

        heading('06  SWD TEST PADS + ESD', 309.88, 165.1, 93.98)
        # The reference pads occupy the open left column of this section.
        # Existing SWD protection remains on the three signal pads.
        for ref, y in [('J10', 191.77), ('J11', 217.17)]:
            if ref in original:
                pad(ref, 328.93, y)
        for ref, diode, y in [('J7', 'D6', 179.07), ('J8', 'D7', 204.47), ('J9', 'D8', 229.87)]:
            pad(ref, 377.19, y, protection=diode, drop=7.62)

        rule(15.24, 269.24, 289.56)
        text('C1: 5V_LED / U4 output bulk capacitor (section 01). D1 clamps raw 12V_IN; FB1 feeds filtered 12V.', 15.24, 273.05)
        text('Cable: 12V, GND, TXP, TXN, RXP, RXN. Piezo coax bypasses this PCB. Matching net labels are connected.', 15.24, 278.13)
        text('RS-422 bus TVS omitted; 22 ohm series retained. D1 protects supply, D6-D8 protect SWD. IEC immunity requires physical validation.', 15.24, 283.21)
    else:
        # Continue to support the original 26-part design for archived builds.
        heading('04  POWER SUPPLIES', 15.24, 165.1, 229.87)
        ic('U4', 76.2, 195.58)
        ic('U5', 187.96, 195.58)
        passive('C13', 27.94, 195.58)
        passive('C14', 232.41, 195.58)
        text('12V -> U4 -> 5V_LED -> U5 -> 3V3', 20.32, 221.615, 1.5)
        text('C1: 5V_LED bulk / U4 output capacitor (section 01).', 20.32, 228.6)
        for net, x in [('12V', 86.36), ('GND', 139.7)]:
            flag = auxiliary_symbol('SleepBud:PWR_FLAG')
            y = 246.38
            move(flag, x, y, val_at=(x-5.08, y-5.08))
            wire(x, y, x+20.32, y)
            power(net, x+20.32, y)
        text('External supply flags', 20.32, 241.3)
        heading('05  CABLE PADS', 260.35, 165.1, 68.58)
        for ref, y in [('J1', 184.15), ('J2', 194.31), ('J3', 207.01), ('J4', 217.17), ('J5', 229.87), ('J6', 240.03)]:
            pad(ref, 297.18, y)
        heading('06  SWD TEST PADS', 341.63, 165.1, 62.23)
        for ref, y in [('J7', 181.61), ('J8', 191.77), ('J9', 201.93), ('J10', 212.09), ('J11', 222.25)]:
            if ref in original:
                pad(ref, 377.19, y)
        text('J7: PA13 / SWDIO', 344.17, 235.585)
        text('J8: PA14 / SWCLK', 344.17, 240.665)
        text('J9: reset / NRST', 344.17, 245.745)
        rule(15.24, 260.35, 240.03)
        text('BOARD / INTERCONNECT NOTES', 15.24, 264.16, 1.5, True)
        text('4-layer PCB, 13.5 mm disc. U1 is the optical PPG module.', 15.24, 270.51)
        text('Cable: 12V, GND, TXP, TXN, RXP, RXN. Piezo coax bypasses this PCB.', 15.24, 275.59)
        text('Matching net labels are connected. Crosses mark intentionally unused pins.', 15.24, 280.67)

    sch.extend(items)
    target.write_bytes(('(kicad_sch\n' + '\n'.join('  '+dump(n) for n in sch[1:]) + '\n)\n').encode('utf-8'))
    # Restore the missing project-local symbol library from the embedded symbols.
    local_lib = ['kicad_symbol_lib', ['version', '20250114'], ['generator', Quoted('kicad_symbol_editor')], ['generator_version', Quoted('9.0')]]
    for s in children(library, 'symbol'):
        s = deepcopy(s)
        s[1] = Quoted(str(s[1]).split(':', 1)[-1])
        local_lib.append(s)
    target.with_name('SleepBud.kicad_sym').write_bytes((dump(local_lib)+'\n').encode('utf-8'))
    print(f'Wrote {target}; preserved {sum(not r.startswith("#") for r in original)} component identities.')


if __name__ == '__main__':
    source = Path(sys.argv[1]) if len(sys.argv) > 1 else Path(__file__).with_name('ppg_pcb_v08.kicad_sch')
    target = Path(sys.argv[2]) if len(sys.argv) > 2 else source
    tidy(source, target)

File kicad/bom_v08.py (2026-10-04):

#!/usr/bin/env python3
"""Export the current schematic BOM as grouped CSV/XLSX, without DNP parts.

Run from any directory: python /path/to/MVP-PPG/kicad/bom_v08.py
Requires KiCad 10's kicad-cli and openpyxl. Set KICAD_CLI if it is not on PATH.
Only the requested output directory is written; importing this module does no IO.
"""
from argparse import ArgumentParser
from collections import defaultdict
import csv
import json
import math
import os
from pathlib import Path
import re
import shutil
import subprocess
import sys
import tempfile
from urllib.parse import unquote, urlsplit
import xml.etree.ElementTree as ET

REPO = Path(__file__).resolve().parent.parent
STEM = "MVP-PPG_BOM_부품별통합_DNP제외_값표준화_v2"
HEADERS = ["No.", "레퍼런스", "수량", "값", "MPN", "제조사", "패키지", "참고 데이터시트", "비고"]
PACKAGE = {
    "SleepBud:MAXM86161_OLGA-14": "OLGA-14, 2.9 × 4.3 mm",
    "Package_DFN_QFN:ST_UFQFPN-20_3x3mm_P0.5mm": "UFQFPN-20, 3 × 3 mm, P0.5 mm",
    "Package_TO_SOT_SMD:SOT-23-5": "SOT-23-5",
    "SleepBud:TSOT23-6_MaxLinear": "TSOT-23-6",
    "Package_TO_SOT_SMD:SOT-23": "SOT-23",
    "Package_DFN_QFN:DFN-8-1EP_2x3mm_P0.5mm_EP0.61x2.2mm": "DFN-8, 2 × 3 mm, P0.5 mm (노출패드)",
    "Capacitor_SMD:C_0402_1005Metric": "0402 (1005)",
    "Capacitor_SMD:C_0201_0603Metric": "0201 (0603)",
    "Resistor_SMD:R_0201_0603Metric": "0201 (0603)",
    "Resistor_SMD:R_0402_1005Metric": "0402 (1005)",
    "Inductor_SMD:L_0402_1005Metric": "0402 (1005)",
    "SleepBud:TVS_SOD882_1x0.6": "SOD-882, 1.0 × 0.6 mm",
    "SleepBud:TI_DPY0002A_1x0.6": "DFN1006-2 (DPY), 1.0 × 0.6 mm",
    "SleepBud:CablePad_D1.2": "구리 납땜 패드 Ø1.2 mm",
    "SleepBud:CablePad_D0.8": "구리 테스트패드 Ø0.8 mm",
}
MANUFACTURER = {
    "MAXM86161EFD+": "Analog Devices (Maxim)", "STM32C011F6U6": "STMicroelectronics",
    "SN65LVDS1DBVR": "Texas Instruments", "SN65LVDT2DBVR": "Texas Instruments",
    "MCP1703A-5002E/MC": "Microchip", "MCP1703A-3302E/MC": "Microchip",
    "SPHV15-01ETG": "Littelfuse", "ESD351DPYR": "Texas Instruments", "BLM15PX601SN1D": "Murata",
    "XR33194ESBTR": "MaxLinear", "XR33183ESBTR": "MaxLinear",
    "CDSOT23-SM712": "Bourns",
    "CRCW0402120RFKEDHP": "Vishay", "CRCW040222R0JNEDHP": "Vishay",
}
# Specifications explicitly recorded in the original v0.8 BOM and carried into
# the user-reviewed 2026-10-01 workbook. Match value AND package: a reused ref
# must not silently inherit these old ratings. Example MPNs remain notes only.
SUPPLEMENTS = {
    ("R", "4.7k", "Resistor_SMD:R_0201_0603Metric"): (
        "4.7k/1%", "기존 v0.8 BOM의 1%", "MPN 미확정"),
    ("C", "10uF 6.3V X5R", "Capacitor_SMD:C_0402_1005Metric"): (
        "10u/6.3V/X5R", "현행 회로도", "MPN 미확정. 기존 BOM 예시: GRM155R60J106ME47"),
    ("C", "1uF 6.3V", "Capacitor_SMD:C_0201_0603Metric"): (
        "1u/6.3V/X5R", "기존 v0.8 BOM의 X5R", "MPN 미확정. 기존 BOM 예시: GRM033R60J105MEA2"),
    ("C", "100nF", "Capacitor_SMD:C_0201_0603Metric"): (
        "100n/16V/X7R", "기존 v0.8 BOM의 16V/X7R", "MPN 미확정. 기존 BOM 예시: GRM033R71C104KE14"),
    ("C", "1uF 25V X7R", "Capacitor_SMD:C_0402_1005Metric"): (
        "1u/25V/X7R", "현행 회로도", "MPN 미확정. 기존 예시 GRM155R61E105KA12는 X7R 적합성 확인 필요"),
}
SUPPLEMENT_REFS = {
    "4.7k": {"R1", "R2"}, "10uF 6.3V X5R": {"C1"},
    "1uF 6.3V": {"C4", "C5", "C12", "C14"},
    "100nF": {"C6", "C7", "C11"}, "1uF 25V X7R": {"C13"},
}
LDO_DATASHEET = "https://ww1.microchip.com/downloads/en/DeviceDoc/20005122B.pdf"


def ref_key(ref):
    return tuple(int(s) if s.isdigit() else s for s in re.split(r"(\d+)", ref))


def compact_value(value, family):
    """Keep the electrical rating; omit only the requested unit/tolerance text."""
    value = value.strip().replace("µ", "u").replace("μ", "u")
    if family not in {"R", "C", "L"}:
        return value
    value = re.sub(r"(?<=\d)\s+(?=[pnumkM]?(?:Ω|[Rr]\b|[Oo]hms?\b|F\b|H\b|V\b|W\b|A\b))", "", value)
    value = re.sub(r"(?<=\d)\s+(?=[pnumkM]\b)", "", value)
    value = re.sub(r"\s*/\s*|\s+", "/", value)
    if family == "R":
        value = re.sub(r"(?<=\d)([mkM]?)(?:Ω|[Rr]|[Oo]hms?)", r"\1", value)
        value = re.sub(r"/(?:±)?5%($|/)", r"\1", value)
    elif family == "C":
        value = re.sub(r"(?<=[0-9pnuµm])F\b", "", value)
    else:
        value = re.sub(r"(?<=[0-9pnuµm])H\b", "", value)
    return value.replace("±", "")


def datasheet_filename(source):
    name = unquote(urlsplit(source.replace("\\", "/")).path).rsplit("/", 1)[-1]
    return name if name.lower().endswith(".pdf") else ""


def cli_path():
    configured = os.environ.get("KICAD_CLI")
    if configured:
        return configured
    found = shutil.which("kicad-cli") or shutil.which("kicad-cli.exe")
    if found:
        return found
    for name in ("kicad-cli", "kicad-cli.exe"):
        sibling = Path(sys.executable).with_name(name)
        if sibling.is_file():
            return str(sibling)
    raise RuntimeError("KiCad 10 kicad-cli is required; set PATH or KICAD_CLI")


def export_schematic(schematic):
    with tempfile.TemporaryDirectory(prefix="ppg-bom-") as work:
        netlist = Path(work) / "current.xml"
        result = subprocess.run(
            [cli_path(), "sch", "export", "netlist", "--format", "kicadxml",
             "--output", str(netlist), str(schematic)],
            capture_output=True, text=True, check=False,
        )
        if result.returncode:
            raise RuntimeError(f"KiCad netlist export failed ({result.returncode}):\n{result.stdout}{result.stderr}")
        return ET.parse(netlist).getroot()


def read_parts(xml):
    parts, excluded = [], []
    seen = set()
    for comp in xml.findall("components/comp"):
        ref = comp.attrib["ref"]
        if ref in seen:
            raise ValueError(f"Duplicate schematic reference: {ref}")
        seen.add(ref)
        properties = {p.attrib["name"] for p in comp.findall("property")}
        if properties & {"dnp", "exclude_from_bom"} or ref.startswith("#"):
            excluded.append({"Reference": ref, "DNP": "dnp" in properties,
                             "ExcludeFromBOM": "exclude_from_bom" in properties})
            continue
        fields = {f.attrib["name"]: f.text or "" for f in comp.findall("fields/field")}
        parts.append({
            "Reference": ref, "Value": comp.findtext("value", ""),
            "Footprint": comp.findtext("footprint", ""), "MPN": fields.get("MPN", ""),
            "Datasheet": fields.get("Datasheet", comp.findtext("datasheet", "")),
            "Description": fields.get("Description", comp.findtext("description", "")),
            "Manufacturer": fields.get("Manufacturer", fields.get("제조사", "")),
        })
    if not parts:
        raise ValueError("The schematic contains no included BOM components")
    return sorted(parts, key=lambda p: ref_key(p["Reference"])), excluded
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

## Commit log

2026-09-30 Document PPG v0.8 checkpoint and pending ESD PCB work
2026-09-30 Save PPG v0.8 schematic cleanup and ESD/bead work in progress
    Add the A3 schematic layout, ESD/FB1 schematic draft, design and generation scripts, baseline PCB/manufacturing outputs, and validation reports.
    README explicitly records that the new protection footprints and PCB routing are unfinished and the manufacturing outputs are pre-ESD baseline files.
    [ppg_pcb_v08-B_Cu.gbl, ppg_pcb_v08-B_Fab.gbr, ppg_pcb_v08-B_Mask.gbs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]
2026-10-04 Import RS-422 project snapshot from MVP-PPG.zip
    Preserve all 375 archive files, including KiCad sources, BOM, documentation, datasheets and historical snapshots.
    Validation: ZIP CRC verified; committed paths and file hashes match the archive.
    Source archive SHA-256: 3fbf3dc2505b0eca75517d05229e315a4e9136078cfb812aac535ee66e8536a6
    [MVP-PPG_BOM_부품별통합_DNP제외_값표준화_v2.xlsx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]
2026-10-05 Update PPG schematic with 0603 decoupling capacitors
    Add C15/C16 100nF 16V X7R capacitors on 3V3 and include pending LDO_EN-to-PA7 and front SWD pad schematic changes. Preserve existing SWD ESD nets and symbol identities.
    Publish generator dependencies, schematic previews, ERC results, and netlist verification. Native ERC reports zero violations; regenerated component data and all 123 numbered pin nets match.
    PCB routing remains paused. PCB, project/rule files, BOM, and manufacturing outputs are intentionally excluded and remain unsynchronized with this schematic.
    [ppg_pcb_v08.kicad_sch]
2026-10-19 Save PPG routing, UART adapter, BOMs and 10-set panel
    Record the current PPG schematic and routed six-layer PCB, UART adapter
    with mounting holes, and default 0.25 mm via drill policy.
    Include UART quantity BOMs in the requested PPG format and the validated
    10-set PPG/UART panel Gerbers, drill files, placement coordinates and
    review history. Preserve earlier manufacturing inputs and exclude local
    backups, editor state and spreadsheet inspection caches.
    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
2026-10-24 docs(firmware): clarify exact UART rate and propose PC CLI
